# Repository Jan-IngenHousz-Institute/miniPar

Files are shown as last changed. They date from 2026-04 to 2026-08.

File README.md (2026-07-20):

# Mini PAR meter - minimum tool to get a good numerical sense of light intensity

vis

# Commands

Commands are sent as plain text terminated with `\n`. JSON mode is also supported — send a valid JSON object and the device will respond in JSON.

* `hello`
    - Response: `MiniPAR,1.1` (plain) / `{"device":"MiniPAR","version":"1.1"}` (JSON)
* `reboot`
    - Restarts the device. Prints boot info ending with `Ready`.
* `delay_ms,<value>`
    - Example: `delay_ms,500`
    - Blocks for `<value>` milliseconds, then responds with the delay value: `500` (plain) / `{"delay_ms":500}` (JSON). Missing/negative value is treated as `0`.
* `battery`
    - Response: `NaN` (plain) / `{"battery":"NaN"}` (JSON)
    - Battery measurement not yet implemented.
* `i2c_scan`
    - Response: comma-separated list of I2C addresses that ACK (e.g. `0x39`)
* `spec[,<count>]`
    - Response: `{"spectrometer":{"model":"AS7341","channels":{"f1_415":1.2345,"f2_445":6.7890,...},"par":123.45}}` (JSON) / `model,ch0,ch1,...,par` (plain)
    - Returns **basic counts** per channel: `raw_reading / gain / integration_time` (counts per second per gain unit). Values are comparable across different gain and integration-time settings.
    - Also includes the calculated PAR value (same as the `par` command), computed from this same reading.
    - `<count>` repeats the measurement that many times (omit, or `1`, for a single reading); each reading is printed as soon as it's taken. With `<count> > 1`: JSON response becomes an array of the single-reading objects (`[{"spectrometer":{...}},{"spectrometer":{...}},...]`); plain response is the single-reading lines joined with `;` on one line.
* `spec_raw`
    - Response: same format as `spec` but raw unscaled integer counts (no normalization applied).
* `spec_flash,<mA>`
    - Example: `spec_flash,10`
    - Dark read → LED on → lit read. Response: `dark:<values>;lit:<values>;diff:<values>` (plain).
* `spec_set_atime,<0-255>`
    - Set spectrometer ATIME integration register. Response: the value set.
* `spec_set_astep,<0-65534>`
    - Set spectrometer ASTEP register. Response: the value set.
* `spec_set_gain,<0-10 (AS7341) | 0-12 (AS7343)>`
    - Set spectrometer gain index. Response: the value set.
* `spec_status` or `status`
    - Response: `model=<name>,available=<0|1>,atime=<val>,astep=<val>,gain=<val>` (plain)
* `set_led,<mA>`
    - Example: `set_led,20`
    - Response: `{"spectrometer":{"led_current_ma":20}}` (JSON) / actual mA set (plain)
    - LED current capped at 20 mA.
* `par[,<count>]`
    - Response: `123.45`
    - PAR value in µmol/m²/s, scaled by linear calibration: `y = a·par_raw + b`
    - `<count>` repeats the measurement that many times (omit, or `1`, for a single reading); each reading is printed as soon as it's taken. With `<count> > 1`: JSON response becomes an array (`[{"par":1.2},{"par":3.4},...]`); plain response is the values joined with `;` on one line.
* `par_raw`
    - Response: `1.23`
    - Weighted dot product of **basic counts** (raw / gain / integration_time) and per-channel PAR coefficients. Independent of gain and integration-time settings.
* `cal_par_slope,<value>`
    - Example: `cal_par_slope,10.0`
    - Response: `{"calibration":{"slope":10.0}}`
    - Set the `a` coefficient for `y = ax + b` scaling. Persisted to NVS.
* `cal_par_intercept,<value>`
    - Example: `cal_par_intercept,2.3`
    - Response: `{"calibration":{"intercept":2.3}}`
    - Set the `b` coefficient for `y = ax + b` scaling. Persisted to NVS.
* `get_cal_par`
    - Response: `{"calibration":{"slope":10.0,"intercept":2.3}}` (JSON) / `slope=10.0,intercept=2.3` (plain)
    - Get the current `a` (slope) and `b` (intercept) coefficients for `y = ax + b` scaling.
* `set_spec_coeff,<channel>,<value>`
    - Example: `set_spec_coeff,0,0.614975`
    - Response: `{"spectrometer_coeff":{"channel":0,"value":0.614975}}`
    - Set per-channel PAR coefficient (channel 0–17). Coefficients are applied to **basic counts** (raw / gain / integration_time), so they must account for the desired normalization. Persisted to NVS.
    - Default coefficients are pre-scaled for the default AS7341 settings (ATIME=100, ASTEP=999, GAIN=2×); re-derive from calibration if defaults are changed.
* `get_spec_coeff`
    - Response: `{"spectrometer_coeffs":{"channels":{"0":0.614975,"1":0.053037,...}}}`
    - Get all 18 per-channel PAR coefficients.
* `get_spec_coeff,<channel>`
    - Example: `get_spec_coeff,0`
    - Response: `{"spectrometer_coeff":{"channel":0,"value":0.614975}}`
    - Get a specific per-channel PAR coefficient.
* `set_name,<string>`
    - Response: `{"device_name":"MyDevice"}`
    - Set custom device name. Persisted to NVS.
* `get_name`
    - Response: `{"device_name":"MyDevice"}`
    - Get current device name.

## BME280 (optional temperature/pressure/humidity sensor)

Detected automatically at boot (I2C address `0x76` or `0x77`); all commands below respond with `error:not_available` (plain) / `{"bme280":{"error":"not_available"}}` (JSON) if no BME280 is fitted. Temperature, pressure, and humidity are all enabled by default, at the highest oversampling (x16), IIR filter off, one-shot read mode.

* `bme_status`
    - Response (plain): `continuous=<0|1>,continuous_active=<0|1>,temp_comp=<value>,temp_en=<0|1>,temp_osrs=<0-5>,press_en=<0|1>,press_osrs=<0-5>,hum_en=<0|1>,hum_osrs=<0-5>,iir=<0-4>`
    - Response (JSON): `{"bme280_status":{"available":true,"continuous_mode":false,"continuous_active":false,"temperature_compensation_c":0.00,"temperature":{"enabled":true,"oversampling":5},"pressure":{"enabled":true,"oversampling":5},"humidity":{"enabled":true,"oversampling":5},"iir_filter":0}}`
* `bme_set_temp_enable,<0|1>`
    - Enable/disable temperature in `bme_get_tph` output. Temperature is still sampled internally regardless (pressure/humidity compensation depend on it) — this only affects reporting.
* `bme_set_press_enable,<0|1>`
    - Enable/disable pressure in `bme_get_tph` output.
* `bme_set_hum_enable,<0|1>`
    - Enable/disable humidity in `bme_get_tph` output.
* `bme_set_temp_oversample,<0-5>`
    - Oversampling: `0`=off (clamped to `1`, since temperature must always be sampled), `1`=x1, `2`=x2, `3`=x4, `4`=x8, `5`=x16 (default).
* `bme_set_press_oversample,<0-5>`
    - Same scale as above; `0`=channel skipped by the sensor.
* `bme_set_hum_oversample,<0-5>`
    - Same scale as above; `0`=channel skipped by the sensor.
* `bme_set_iir,<0-4>`
    - IIR filter coefficient: `0`=off (default), `1`=x2, `2`=x4, `3`=x8, `4`=x16.
* `bme_set_continuous,<0|1>`
    - `0` (default) = one-shot: every `bme_get_tph` call takes its own forced-mode measurement.
    - `1` = continuous: the chip free-runs in normal mode; `bme_get_tph` blocks only on the first call after enabling (waiting for that first conversion), then returns whatever the chip's background cycle last produced.
* `bme_set_temp_comp,<value>`
    - Set the temperature compensation offset in °C, added to every raw temperature reading (and folded into the pressure/humidity compensation math) to null out self-heating bias. Persisted to NVS.
* `bme_get_temp_comp`
    - Response: current temperature compensation offset in °C.
* `bme_get_tph[,<count>]` (alias: `tph[,<count>]`)
    - Response (plain): `<temperature_c>,<pressure_hpa>,<humidity_pct>` — positional CSV, blank field for a disabled channel.
    - Response (JSON): `{"bme280":{"temperature_c":23.45,"pressure_hpa":1013.25,"humidity_pct":45.20}}` — `null` for a disabled channel.
    - Behavior depends on `bme_set_continuous`: one-shot mode (default) takes a fresh forced-mode reading every call; continuous mode waits for the first conversion only on the first call after being enabled, then returns the most recent free-running reading on every call after that.
    - `<count>` repeats the measurement that many times (omit, or `1`, for a single reading); each reading is printed as soon as it's taken. With `<count> > 1`: JSON response becomes an array of the single-reading objects; plain response is the single-reading CSV rows joined with `;` on one line.

# Status LED (GPIO 10)

The LED on GPIO 10 provides a visual indication of spectrometer state:

| LED state | Meaning |
|---|---|
| Off | No spectrometer detected at boot |
| Solid on | Spectrometer detected, all channels within range |
| Blinking 20 Hz | At least one spectrometer channel is saturated |

Saturation is checked automatically on every spectrometer read (`spec`, `spec_raw`, `par`, `par_raw`, etc.). The LED returns to solid-on as soon as the next read finds all channels within range. Reduce gain or integration time (`spec_set_gain`, `spec_set_atime`, `spec_set_astep`) to clear saturation.

# Protocol

* Command terminator: `\n` (`\r` is ignored)
* PAR units: µmol/m²/s
* **Basic counts**: `raw_reading / gain / integration_time`, where `integration_time = (ATIME+1) × (ASTEP+1) × 2.78 µs`. Used by `spec`, `par`, and `par_raw` — values are gain/integration-time independent.
* **Default AS7341 settings**: ATIME=100, ASTEP=999, GAIN=2× (integration time ≈ 280.8 ms). Per-channel PAR coefficients stored in NVS are calibrated for basic counts at these defaults.

FW Design (L. Grabowski, L. Caracciolo),

HW Design (L. Grabowski)

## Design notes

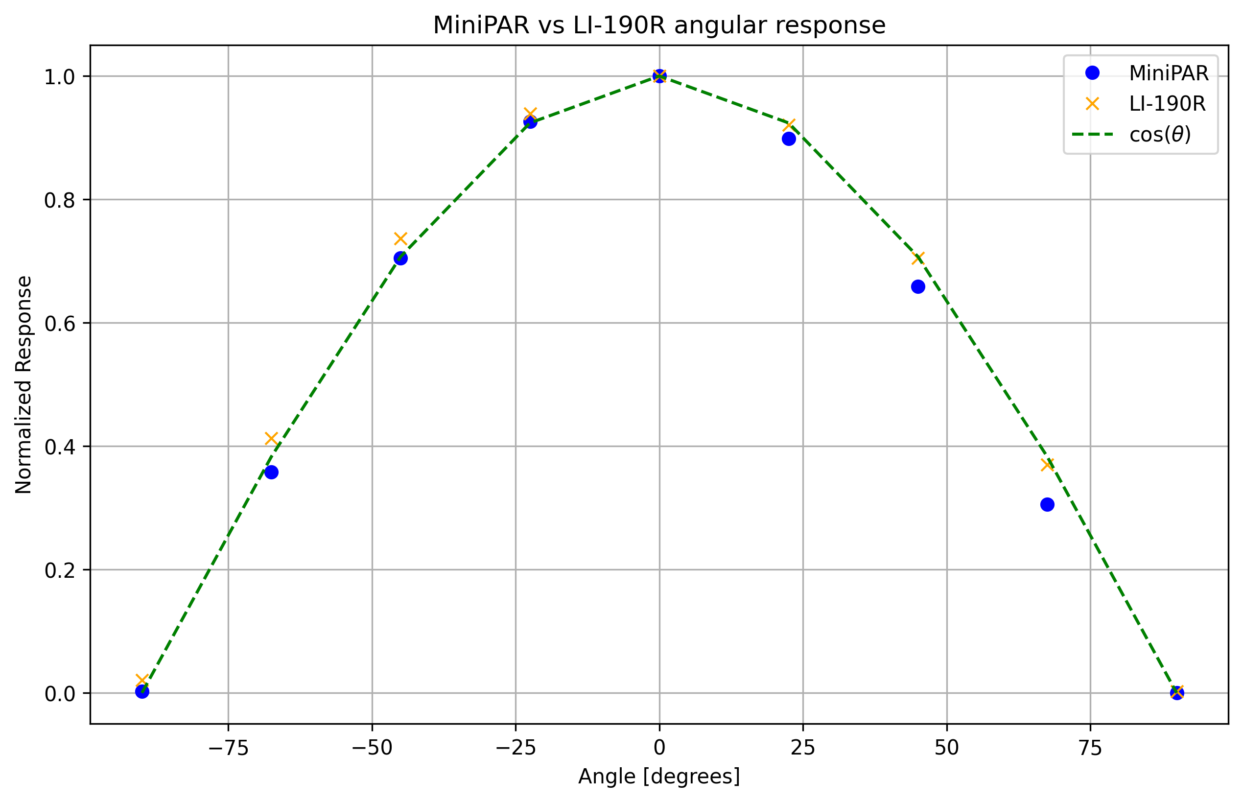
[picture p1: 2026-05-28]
Scripts/angular_calbration_Vertical_2.png

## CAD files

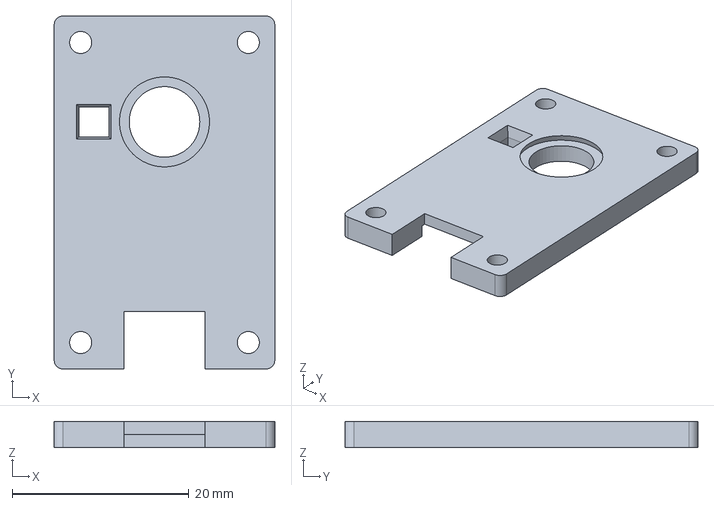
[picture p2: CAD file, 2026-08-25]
Case/casing.FCStd
25.0 x 40.0 x 3.00 mm

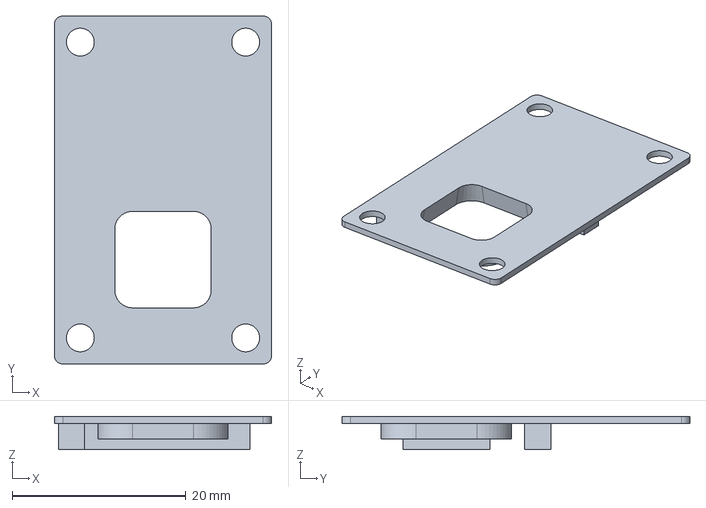
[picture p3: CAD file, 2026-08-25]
Case/ms_backplate.FCStd
25.0 x 40.0 x 3.80 mm

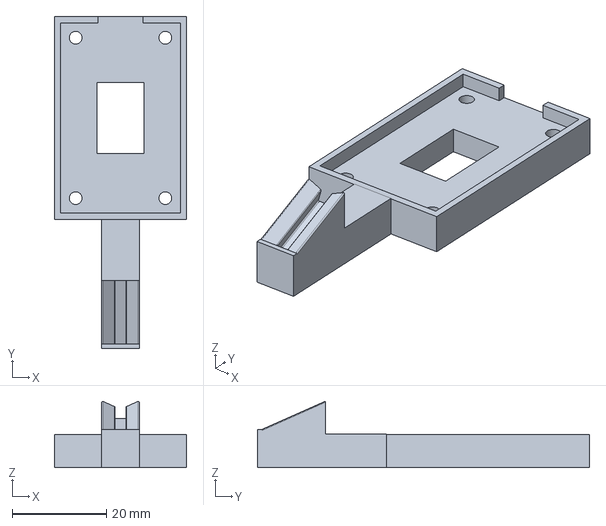
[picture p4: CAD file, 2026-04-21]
Case/Ambit_Minipar_fixture.FCStd
28.0 x 70.4 x 14.1 mm

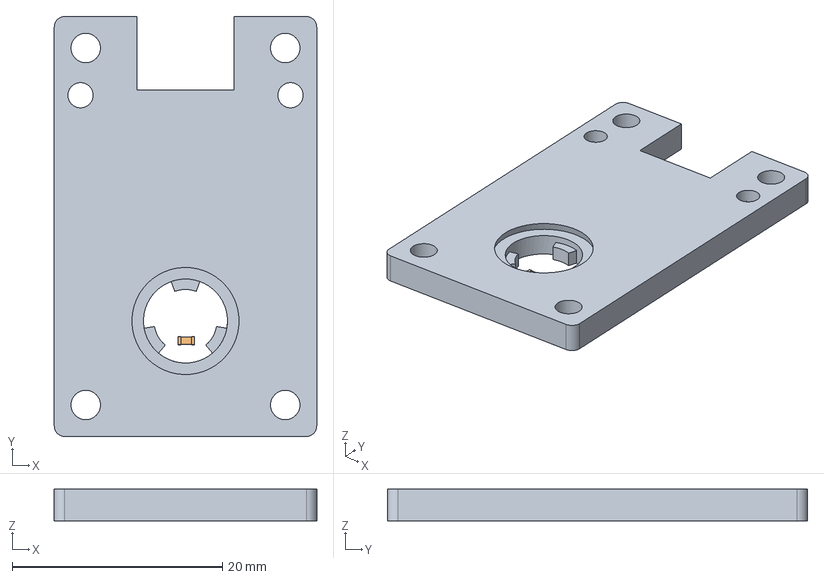
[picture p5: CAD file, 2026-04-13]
Case/diffuserHolder.FCStd
25.0 x 40.0 x 3.00 mm
Insert
C_0603_1608Metric008
R_0603_1608Metric006
R_0603_1608Metric005
C_0603_1608Metric004
C_0603_1608Metric003
R_0603_1608Metric004
R_0603_1608Metric003
QFN-28-1EP_4x4mm_P0.4mm_EP2.4x2.4mm
C_0603_1608Metric001
R_0603_1608Metric002
C_0603_1608Metric
TSOT-23-6

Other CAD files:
Case/casing-Body.3mf

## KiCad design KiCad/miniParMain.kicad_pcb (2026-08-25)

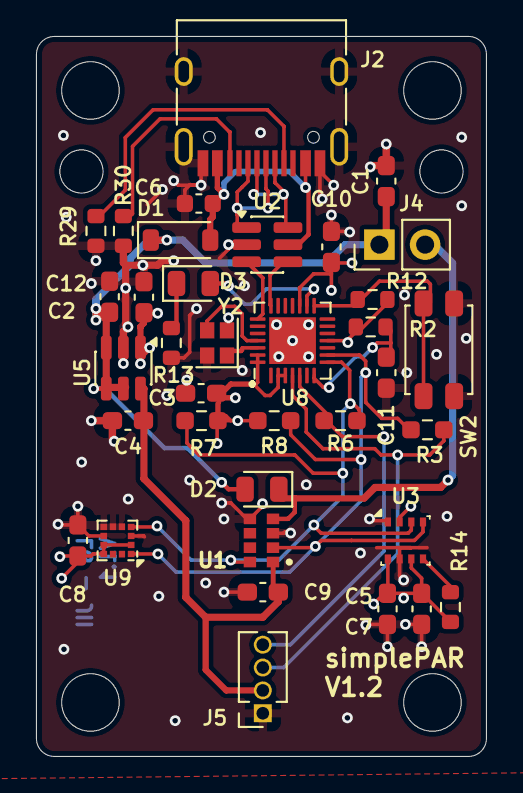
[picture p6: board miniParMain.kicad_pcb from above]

Board: 4 copper layers, 25.0 x 40.0 mm, 36 parts (0 on the bottom side), 23 nets.

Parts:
C1, C2, C3, C4, C5, C7, C8, C9, C10, C11, C12: 2.2u; C_0603_1608Metric_Pad1.08x0.95mm_HandSolder
C6: 10u; C_0603_1608Metric
D1: 1N4148WT; D_SOD-123
D2, D3: LED; D_0805_2012Metric
J2: USB_C_Receptacle; USB_C_Receptacle_HRO_TYPE-C-31-M-12
J4: Conn_01x02_Pin; PinHeader_1x02_P2.54mm_Vertical
J5: secondBoard; PinSocket_1x04_P1.27mm_Vertical
R2, R12, R13, R14, R29, R30: 5.1K; R_0603_1608Metric
R3, R6: 0R; R_0603_1608Metric_Pad0.98x0.95mm_HandSolder
R7, R8: 10K; R_0603_1608Metric_Pad0.98x0.95mm_HandSolder
SW2: SW_Push; SW_SPST_EVQP2_ShortPushTravel_H2.1mm
U1: AS7341-DLGT; PSON80P310X200X110-8N
U2: IP4234CZ6; SC-74-6_1.55x2.9mm_P0.95mm
U3: BME280; Bosch_LGA-8_2.5x2.5mm_P0.65mm_ClockwisePinNumbering
U5: AP7312-1833W6-7; TSOT-23-6
U8: ESP8685; QFN-28-1EP_4x4mm_P0.4mm_EP2.6x2.6mm
U9: LIS2DE12; LGA-12_2x2mm_P0.5mm
Y2: 40MHz; Crystal_SMD_2016-4Pin_2.0x1.6mm

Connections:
BOOT: R12.1, SW2.1, U8.15 (GPIO9/BOOT)
CC1: J2.A5 (CC1), R29.2
CC2: J2.B5 (CC2), R30.2
D+: U2.3, U8.22 (GPIO19/USB_D+)
D-: U2.4, U8.21 (GPIO18/USB_D-)
GND: C1.2, C2.2, C3.2, C4.2, C5.2, C6.1, C7.2, C8.2, C9.2, C10.2, C11.2, C12.2, J2.A1 (GND), J2.A12 (GND), J2.B1 (GND), J2.B12 (GND), J2.S1 (SHIELD), J5.1, R13.1, R29.1, R30.1, SW2.2, U1.3 (GND), U1.5 (PGND), U2.2 (VN), U3.1 (GND), U3.7 (GND), U5.2 (GND), U8.29 (GND), U9.3 (SA0/SDO), U9.5 (RES), U9.6 (GND), U9.7 (GND), U9.8 (GND), Y2.2, Y2.4
LED1ACT: D2.1 (K), J4.2, U1.4 (LDR)
unnamed: D3.2 (A), U8.16 (GPIO10)
unnamed: D3.1 (K), R13.2
unnamed: J2.A6 (D+), J2.B6 (D+), U2.1
unnamed: J2.A7 (D-), J2.B7 (D-), U2.6
unnamed: R14.1, U3.5 (SDO)
unnamed: U8.25 (XTAL_N), Y2.3
unnamed: U8.26 (XTAL_P), Y2.1
SCL: R3.2, R8.1, U1.2 (SCL), U3.4 (SCK), U8.9 (MTMS/GPIO4/ADC1_CH4), U9.1 (SCL/SPC)
SCL_2: J5.4, R6.1, U8.5 (GPIO1/XTAL_32K_N/ADC1_CH1)
SDA: R6.2, R7.1, U1.8 (SDA), U3.3 (SDI), U8.8 (GPIO3/ADC1_CH3), U9.4 (SDA/SDI)
SDA_2: J5.3, R3.1, U8.4 (GPIO0/XTAL_32K_P/ADC1_CH0)
V+: C1.1, C12.1, D1.1 (K), D2.2 (A), J4.1, U5.3 (EN2), U5.4 (EN1), U5.5 (VIN)
V+1.8V: C4.1, C9.1, J5.2, U1.1 (VDD), U5.6 (VOUT_1V8)
V+3V: C2.1, C3.1, C5.1, C7.1, C8.1, C10.1, R2.1, R7.2, R8.2, R12.2, R14.2, U3.2 (CSB), U3.6 (VDDIO), U3.8 (VDD), U5.1 (VOUT_3V3), U8.2 (VDD3P3), U8.3 (VDD3P3), U8.11 (VDD3P3_RTC), U8.17 (VDD3P3_CPU), U8.27 (VDDA), U8.28 (VDDA), U9.2 (~CS), U9.9 (Vdd), U9.10 (Vdd_IO)
Vusb: C6.2, D1.2 (A), J2.A4 (VBUS), J2.A9 (VBUS), J2.B4 (VBUS), J2.B9 (VBUS), U2.5 (VP)
reset_EN: C11.1, R2.2, U8.7 (CHIP_EN)

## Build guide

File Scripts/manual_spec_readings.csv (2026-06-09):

timestamp | tia_par | filter_name | f1_415 | f2_445 | f3_480 | f4_515 | f5_555 | f6_590 | f7_630 | f8_680 | clear | nir
2026-06-01T12:34:18 | 94.16944 | white | 19.0 | 53.0 | 79.0 | 98.0 | 105.0 | 113.0 | 136.0 | 86.0 | 335.0 | 22.0
2026-06-01T12:34:48 | 47.380044 | e002 | 11.0 | 30.0 | 40.0 | 28.0 | 22.0 | 53.0 | 110.0 | 73.0 | 183.0 | 14.0
2026-06-01T12:35:22 | 69.04729 | e003 | 15.0 | 42.0 | 60.0 | 70.0 | 69.0 | 77.0 | 101.0 | 74.0 | 249.0 | 17.0
2026-06-01T12:36:02 | 58.53448 | e004 | 10.0 | 23.0 | 35.0 | 48.0 | 62.0 | 87.0 | 119.0 | 75.0 | 222.0 | 17.0
2026-06-01T12:37:34 | 77.56118 | e007 | 13.0 | 31.0 | 58.0 | 86.0 | 94.0 | 102.0 | 123.0 | 78.0 | 283.0 | 20.0
2026-06-01T12:37:48 | 37.90371 | e008 | 6.0 | 10.0 | 12.0 | 14.0 | 27.0 | 71.0 | 113.0 | 72.0 | 157.0 | 14.0
2026-06-01T12:39:15 | 59.99048 | e009 | 10.0 | 19.0 | 33.0 | 56.0 | 71.0 | 91.0 | 118.0 | 75.0 | 227.0 | 17.0
2026-06-01T12:39:29 | 61.051632 | e010 | 7.0 | 5.0 | 19.0 | 77.0 | 92.0 | 101.0 | 121.0 | 75.0 | 237.0 | 19.0
2026-06-01T12:40:31 | 58.7319 | e013 | 10.0 | 19.0 | 32.0 | 54.0 | 75.0 | 93.0 | 114.0 | 73.0 | 225.0 | 17.0
2026-06-01T12:41:13 | 45.874688 | e015 | 6.0 | 5.0 | 8.0 | 29.0 | 65.0 | 88.0 | 111.0 | 71.0 | 183.0 | 15.0
2026-06-01T12:41:49 | 13.768671 | e017 | 2.0 | 4.0 | 4.0 | 7.0 | 14.0 | 25.0 | 35.0 | 22.0 | 60.0 | 5.0

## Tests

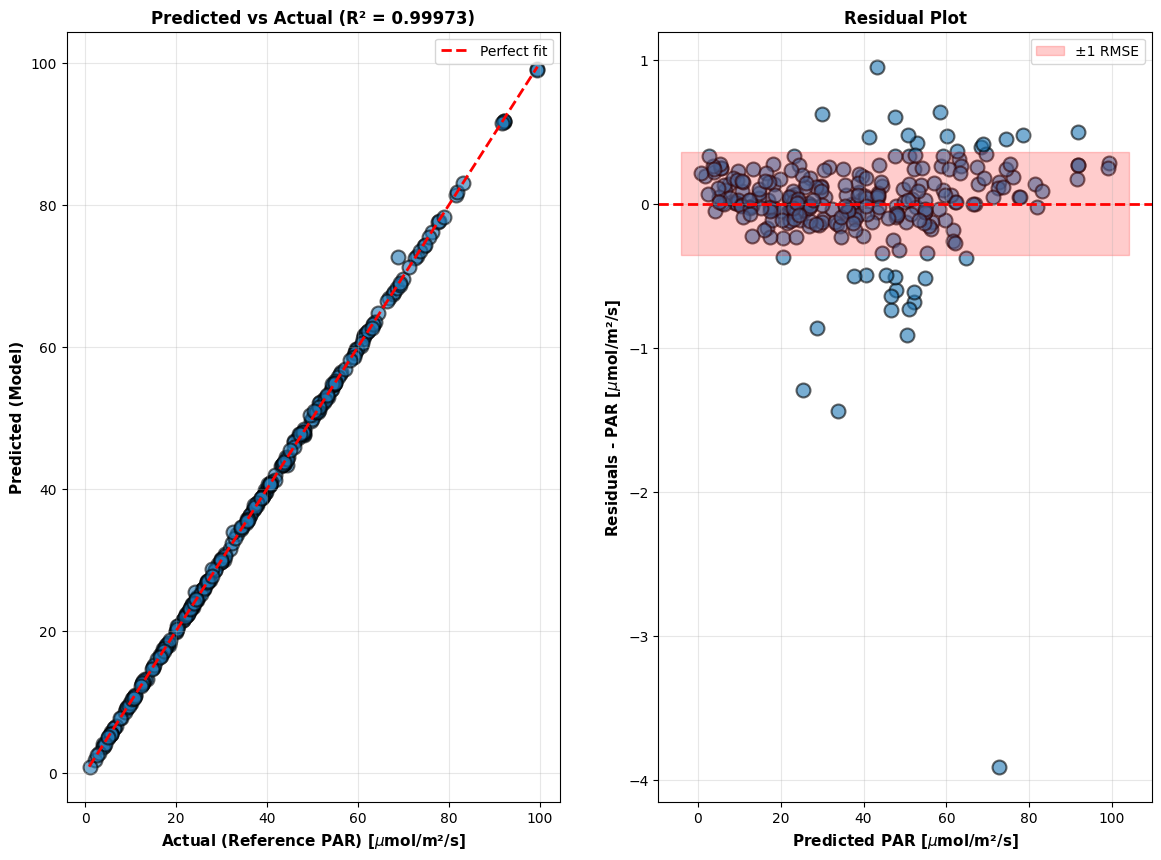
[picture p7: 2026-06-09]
Scripts/calibration_fit_analysis.png

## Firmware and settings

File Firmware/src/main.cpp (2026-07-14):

#include <Arduino.h>
#include <Wire.h>
#include "app/commands.h"
#include "app/spectrometer_api.h"
#include "app/bme280_api.h"
#include "app/led_status.h"
#include "app/device_config.h"


String line;
enum class RxMode { UNKNOWN, LINE, JSON };
String rx;
RxMode mode = RxMode::UNKNOWN;
int braceDepth = 0;   // {}
int bracketDepth = 0; // []
bool inString = false;
char prev = 0;

void resetRx() {
  rx = "";
  mode = RxMode::UNKNOWN;
  braceDepth = 0;
  bracketDepth = 0;
  inString = false;
  prev = 0;
}

void setup() {
  Serial.begin(DEVICE_SERIAL_BAUD);

  ledStatusInit();

  Wire.begin(DEVICE_I2C_SDA_PIN, DEVICE_I2C_SCL_PIN);

  loadpref();
  initSpectrometer();
  initBme280();
  ledStatusSetDetected(spectrometer_available);

  Serial.println(F("Ready"));
}





void loop() {
  ledStatusUpdate();
  while (Serial.available() > 0) {
    char c = (char)Serial.read();
    if (c == '\r')
      continue;

    rx += c;

    // Decide mode once we see the first non-whitespace char
    if (mode == RxMode::UNKNOWN) {
      // find first non-space char in the current buffer
      int i = 0;
      while (i < (int)rx.length() && isspace((unsigned char)rx[i]))
        i++;
      if (i < (int)rx.length()) {
        char first = rx[i];
        if (first == '{' || first == '[') {
          mode = RxMode::JSON; // start JSON mode (typically openJII app series of commands)
        } else {
          mode = RxMode::LINE; // start LINE mode (simple single-line commands)
        }
      }
    }

    // LINE mode: only process on newline
    if (mode == RxMode::LINE) {
      if (c == '\n') {
        rx.trim();
        if (rx.length() > 0)
          handleCommandText(rx);
        Serial.println();
        resetRx();
      }
      continue;
    }

    // JSON mode: track braces/brackets until outermost closes
    if (mode == RxMode::JSON) {
      if (c == '"' && prev != '\\')
        inString = !inString;

      if (!inString) {
        if (c == '{')
          braceDepth++;
        else if (c == '}')
          braceDepth--;
        else if (c == '[')
          bracketDepth++;
        else if (c == ']')
          bracketDepth--;
      }

      prev = c;

      // Only declare "complete" after the top-level JSON object/array closes.
      if (!inString && braceDepth == 0 && bracketDepth == 0) {
        rx.trim();
        bool ok = handleJsonProtocol(rx);
        if (!ok)
          Serial.println(F("{\"error\":\"json_dispatch_failed\"}"));
        resetRx();
      }
      continue;
    }

    // Safety: prevent runaway buffer
    if (rx.length() > 2048) {
      Serial.println("rx_overflow");
      resetRx();
    }
  }
}

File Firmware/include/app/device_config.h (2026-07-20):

#pragma once

// ---------------------------------------------------------------------------
// Device identity — fixed at build time
// ---------------------------------------------------------------------------
#define DEVICE_PRODUCT_NAME     "MiniPAR"
#define DEVICE_VERSION          "1.1"
#define DEVICE_FIRMWARE_VERSION      1.05f
#define DEVICE_FIRMWARE_VERSION_STR  "1.05"

// device ID is a unique identifier for the device, derived from the the MAC address

// Sentinel appended to every JSON output frame (CRC-like footer)
#define DEVICE_FRAME_FOOTER     "7A1E3AA1"

// ---------------------------------------------------------------------------
// Hardware / communication
// ---------------------------------------------------------------------------
#define DEVICE_SERIAL_BAUD      115200
#define DEVICE_I2C_SDA_PIN      3
#define DEVICE_I2C_SCL_PIN      4
#define DEVICE_STATUS_LED_PIN   10

// ---------------------------------------------------------------------------
// Configurable parameters — stored in NVS; these are the compile-time defaults
// ---------------------------------------------------------------------------
#define DEVICE_DEFAULT_NAME     "NoName"
#define DEVICE_NAME_MAX_LEN     20

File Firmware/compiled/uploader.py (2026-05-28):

"""Standalone ESP32-C3 firmware uploader.

The script searches its own folder and every sub-folder for the compiled
firmware images (and the bundled ``esptool.exe``), so it just needs to be
dropped next to -- or one level above -- the compiled files; it does not need
its own copy of them.

It flashes any ESP32-C3 reachable over USB: it lists every serial port, uses
the only one if there is just one, and prompts you to choose when there are
several. esptool confirms the chip is really an ESP32-C3 when it connects.

Cross-platform esptool resolution, forced-or-detected flashing, and an
optional post-flash hardware test.
"""

import os
import subprocess
import sys
import time
import argparse
import re
import importlib
import importlib.util


# ===========================================================================
# CONFIGURATION -- edit these to control how the uploader behaves
# ===========================================================================

# Flashing / test behaviour.
FORCE_FLASH = True   # True: always flash. False: flash only on "invalid header".
RUN_TEST = False      # True: run the post-flash hardware test (test_ambit()).

# Flash speed. Boards behind a real USB-UART bridge (CH340, CP210x, FTDI, ...)
# flash much faster at a high baud. Boards with the ESP32-C3's native
# USB-Serial/JTAG (Espressif VID 0x303A) ignore the serial baud -- the link
# runs at USB speed -- and esptool's mid-flash baud change fails there with
# "No serial data received", so those are flashed at the default 115200.
FLASH_BAUD = 921600          # baud for real USB-UART bridges
NATIVE_USB_BAUD = 115200     # baud for native USB-Serial/JTAG (VID 0x303A)
ESPRESSIF_USB_VID = 0x303A

# Max time to wait for pip when auto-installing a missing dependency.
PIP_INSTALL_TIMEOUT = 300  # seconds

# MLX90632 temperature-sensor acceptance limits.
MIN_TEMP = -10             # deg C, lower bound for a valid reading
MAX_TEMP = 40              # deg C, upper bound for a valid reading
MLX_READ_TIME_LIMIT = 100  # ms, max acceptable sensor read time

# Firmware images the script searches for. Whichever folder (this one or a
# sub-folder) contains all of them is used as the firmware folder. esptool is
# resolved separately by esptool_command(), so it is *not* listed here.
REQUIRED_FILES = [
    "firmware.bin",
    "bootloader.bin",
    "partitions.bin",
    # "boot_app0.bin",
]
# ===========================================================================


def ensure_package(module_name, pip_name=None):
    """Import ``module_name``; if it is missing, install it with pip first.

    This lets the uploader run on a fresh machine without a separate
    ``pip install`` step -- the dependency is fetched automatically the first
    time the script is run.

    :param module_name: the name used in ``import`` (e.g. ``serial``).
    :param pip_name: the package name on PyPI, when it differs from
        ``module_name`` (e.g. ``pyserial``).
    :return: the imported module.
    """
    pip_name = pip_name or module_name
    try:
        return importlib.import_module(module_name)
    except ImportError:
        pass

    print(f"[INFO] Required package '{pip_name}' is not installed; "
          f"installing it now (one-time setup)...")
    for extra in ([], ["--user"]):
        try:
            subprocess.run(
                [sys.executable, "-m", "pip", "install", *extra, pip_name],
                check=True,
                timeout=PIP_INSTALL_TIMEOUT,
            )
            break
        except subprocess.CalledProcessError:
            continue
        except subprocess.TimeoutExpired:
            print(f"[WARN] pip install of '{pip_name}' timed out after "
                  f"{PIP_INSTALL_TIMEOUT}s.")
            continue

    # A freshly installed package may not be on the import path yet.
    importlib.invalidate_caches()
    try:
        import site
        for path in (*site.getsitepackages(), site.getusersitepackages()):
            if path not in sys.path:
                sys.path.append(path)
    except Exception:
        pass

    try:
        return importlib.import_module(module_name)
    except ImportError:
        print(f"[ERROR] Could not install '{pip_name}' automatically. Please "
              f"install it manually with:\n"
              f"        {sys.executable} -m pip install {pip_name}")
        sys.exit(1)


# Make sure third-party dependencies are present before importing them.
ensure_package("serial", "pyserial")
if os.name != "nt":
    # Windows uses the bundled esptool.exe; other platforms need the package.
    ensure_package("esptool")

import serial
import serial.tools.list_ports

# Folder this script lives in. The firmware files (and esptool.exe) are looked
# up here and in every sub-folder, so the script can sit next to -- or one
# level above -- the compiled firmware.
HERE = os.path.dirname(os.path.abspath(__file__))

# Folder that actually holds the compiled firmware. Discovered at runtime by
# main(); esptool_command() prefers an esptool.exe found inside it.
FIRMWARE_DIR = None


def find_file(start_dir, filename):
    """Return the path to the first ``filename`` found in ``start_dir`` or any
    of its sub-folders, or ``None`` if it is nowhere to be found.
    """
    for root, _dirs, files in os.walk(start_dir):
        if filename in files:
            return os.path.join(root, filename)
    return None


def find_firmware_dir(start_dir, required_files):
    """Search ``start_dir`` and its sub-folders for a folder that contains
    every file in ``required_files``.

    :return: the absolute path of the first matching folder, or ``None``.
    """
    required = set(required_files)
    for root, _dirs, files in os.walk(start_dir):
        if required.issubset(files):
            return os.path.abspath(root)
    return None


def esptool_command():
    """Return the argv prefix used to invoke esptool, cross-platform.

    Prefers a bundled ``esptool.exe`` on Windows -- looked for inside the
    firmware folder first, then this script's folder and every sub-folder --
    otherwise runs the installed ``esptool`` Python package via
    ``python -m esptool`` (Linux/macOS, or Windows without the bundled binary).

    :raises RuntimeError: if no esptool is available.
    """
    if os.name == "nt":
        local_exe = None
        if FIRMWARE_DIR:
            local_exe = find_file(FIRMWARE_DIR, "esptool.exe")
        if not local_exe:
            local_exe = find_file(HERE, "esptool.exe")
        if local_exe:
            return [local_exe]
    if importlib.util.find_spec("esptool") is not None:
        return [sys.executable, "-m", "esptool"]
    raise RuntimeError(
        "esptool not found. Install it with `pip install esptool`, "
        "or place esptool.exe next to this script or in a sub-folder "
        "(Windows only)."
    )
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

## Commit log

2026-04-13 cover whole PCB
    [diffuserHolder.FCStd]
2026-04-13 add calibration fixture
    [Minipar_ambit_fixture.FCStd]
2026-04-21 add device name to hanlde multiple devices
2026-04-21 cleaned calibration script, helpers moved to separate file
2026-04-21 modify script for 2 PAR sensors
2026-04-21 Add files via upload
    Corrected the old version - this one should fit better (keeps in mind some extra flex size when printing)
    [Ambit_Minipar_fixture.FCStd]
2026-04-21 Delete Case/Minipar_ambit_fixture.FCStd
    Removal of the old version
    [Minipar_ambit_fixture.FCStd]
2026-05-03 working connection device to openJII by OTG usb-serial
2026-05-28 script and result for the angular callibration of the
    [angular_calbration_Vertical_2.csv]
2026-05-28 manual calibration
2026-05-28 clean manual calibration script
2026-06-01 MiniPAR + Licor Holder for cosine correction
    [Li+MiniP_holderV3.FCStd, Li+MiniP_rotatingV3.FCStd]
2026-06-01 manual collection of channel reading for filtered light
    [manual_spec_readings.csv]
2026-06-02 update of notebook for the multiple filter regression test
2026-06-09 calibrate_spec stabilization
2026-06-29 par reading based on basic count, add LED power and saturation indicator
2026-08-25 add bme to PCB - update the casing
    [casing-Body.3mf, casing.FCStd, miniParMain.kicad_pcb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]
2026-08-31 feature(data_calibration): added data for the calibration
    [multi_par_spec.csv, multi_par_spec_lr1b.csv, multi_spec_readings_ValidDevice_1.csv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]
